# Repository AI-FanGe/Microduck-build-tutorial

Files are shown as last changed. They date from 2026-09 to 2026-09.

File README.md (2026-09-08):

# Microduck

<p align="center">
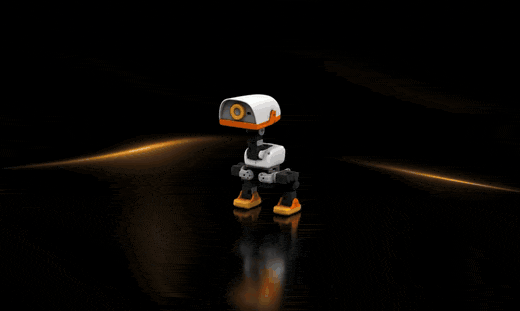
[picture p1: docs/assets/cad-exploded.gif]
Microduck 结构爆炸图
  
</p>
<p align="center">
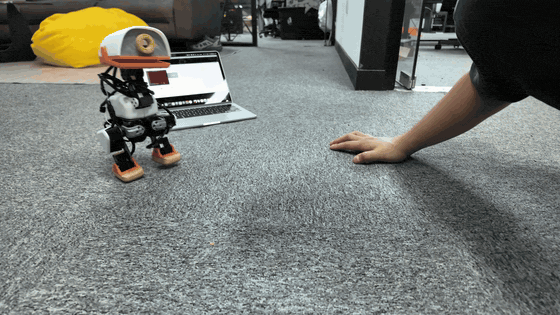
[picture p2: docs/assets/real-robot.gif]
Microduck 人机互动
  
</p>
<p align="center">
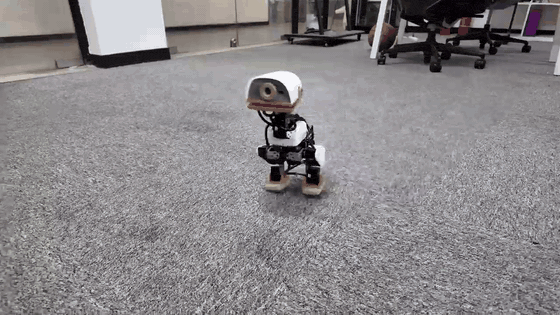
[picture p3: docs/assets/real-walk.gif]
Microduck 实机行走
  
</p>

Microduck 是一个小型双足机器人项目，包含两部分：

- `microduck/`: Raspberry Pi Zero 2 W 上运行的部署代码，负责读取 IMU、读取手柄/键盘输入、驱动 Dynamixel 舵机，并加载 ONNX 行走策略。
- `mjlab_microduck/`: 基于 MuJoCo/MjLab 的强化学习训练环境，用来训练并导出 `walk.onnx`。

本 README 面向装机和第一次运行：准备硬件、接线、刷写 `microduck.img.xz`、初始化 Wi-Fi、SSH 登录、运行模型，以及后续更新代码。3D打印的文件在项目中。

视频教程：https://www.youtube.com/watch?v=Vep8AjoCnEM

## 致谢

感谢开源项目 [microban](https://github.com/Rhoban/microban) 和 [microduck](https://github.com/pollen-robotics/microduck)。本项目的机械结构、部署思路、仿真训练和实机行走流程都受益于这些开源工作。

## 项目状态

当前发布镜像已经内置：

- Raspberry Pi OS Lite 64-bit。
- 主机名 `microduck`。
- 默认用户 `user`。
- 部署目录 `~/microduck`。
- Python 虚拟环境 `~/microduck/.venv`。
- 行走模型 `~/microduck/src/agents/walk.onnx`。
- 无头手柄服务 `microduck-gamepad.service`，可开机后用手柄启动模型。

当前预构建镜像：

- [microduck.img.xz](https://github.com/AI-FanGe/Microduck-build-tutorial/releases/download/image.v1/microduck.img.xz)

## BOM

下面是组装一台 Microduck 的主要物料。价格会随地区、采购渠道和批量变化，仅用于估算。

| 类别 | 物料 | 数量 | 说明 |
| :--- | :--- | :---: | :--- |
| 控制板 | Raspberry Pi Zero 2 W | 1 | 运行控制程序、蓝牙手柄、Wi-Fi 和 SSH。 |
| 舵机控制板 | ROBOTIS OpenRB-150 | 1 | 通过 USB 连接 Raspberry Pi，负责和 XL330 舵机总线通信。代码会优先自动查找 `/dev/serial/by-id/usb-ROBOTIS_OpenRB-150_*`。 |
| 舵机 | Dynamixel XL330-M288-T | 14 | 当前行走代码使用 14 个舵机：双腿 10 个，头/颈 4 个。若安装嘴部舵机，可使用 ID 15，但当前行走模型不依赖它。 |
| 电池 | 成品 6V 可充电电池 | 1 | 当前硬件直接使用成品 6V 电池包供电，不使用两节 18650 自制电池组。请确认电池能提供足够瞬时电流。 |
| 开关 | 电源开关 | 1 | 控制机器人主电源。 |
| 存储 | 16GB 或更大 microSD 卡 | 1 | 推荐使用质量稳定的新卡。镜像刷写后首次启动会自动扩展分区。 |
| IMU | BNO080/BNO085/BNO086 模块 | 1 | 通过 I2C 读取姿态，代码会自动探测常见地址。 |
| 结构件 | 3D 打印件 | 1 套 | 使用 `microduck/cad/` 中的模型打印。推荐 PLA。 |
| 螺丝 | M2/M2.5 自攻螺丝 | 若干 | 舵机固定、舵盘固定、结构件连接。建议多备。 |
| 线材 | Dynamixel 3-pin 线| 若干 | 舵机串联、电源连接、分线。 |

## 舵机 ID

控制代码期望的 ID 映射如下。烧录镜像之前或第一次运行之前，应先用 Dynamixel Wizard 设置好每个舵机。

| ID | 名称 | 位置 |
| :---: | :--- | :--- |
| 1 | `right_ankle` | 右踝 |
| 2 | `right_knee` | 右膝 |
| 3 | `right_hip_pitch` | 右髋俯仰 |
| 4 | `right_hip_roll` | 右髋横滚 |
| 5 | `right_hip_yaw` | 右髋偏航 |
| 6 | `left_ankle` | 左踝 |
| 7 | `left_knee` | 左膝 |
| 8 | `left_hip_pitch` | 左髋俯仰 |
| 9 | `left_hip_roll` | 左髋横滚 |
| 10 | `left_hip_yaw` | 左髋偏航 |
| 11 | `head_pitch` | 头部俯仰 |
| 12 | `neck_pitch` | 颈部俯仰 |
| 13 | `head_yaw` | 头部偏航 |
| 14 | `head_roll` | 头部横滚 |
| 15 | `mouth` | 可选嘴部舵机，当前行走策略不使用 |

Dynamixel Wizard 推荐参数：

- Protocol: `2.0`
- Baud Rate: `1Mbps`
- Return Delay Time: `0`
- PWM Slope: `255`
- Shutdown: 去掉输入电压错误触发项，避免电池电压波动时误停

## 接线图

### 电源接线

电源链路如下：

```mermaid
flowchart LR
    BAT[成品 6V 可充电电池] --> SW[电源开关]
    SW --> OPENRB[OpenRB-150 电源输入]
    OPENRB --> BUS[XL330 舵机总线]
    PI[Raspberry Pi Zero 2 W] -->|USB 数据线| OPENRB
    BAT --> REG[5V 稳压/USB 供电]
    REG --> PI
```

检查要点：

- 上电前用万用表确认正负极。
- 当前硬件使用成品 6V 可充电电池，不需要自制 2S 电池组、BMS 和 2S 充电板。
- OpenRB-150 负责 XL330 舵机通信，Raspberry Pi 通过 USB 连接 OpenRB-150。
- Raspberry Pi 需要稳定 5V 供电；舵机/OpenRB-150 使用 6V 电池侧供电。两侧必须共地，具体以你的电源模块和 OpenRB-150 接法为准。
- 焊点需要热缩管或热熔胶绝缘，避免短路。

### 舵机总线

XL330 使用 3-pin 串联总线。OpenRB-150 接出后可通过分线分到左右腿和头部。

```mermaid
flowchart TD
    OPENRB[OpenRB-150 Dynamixel Port]
    OPENRB --> SPLIT[分线]
    SPLIT --> R5[右腿链: ID 5 -> 4 -> 3 -> 2 -> 1]
    SPLIT --> L10[左腿链: ID 10 -> 9 -> 8 -> 7 -> 6]
    SPLIT --> H12[头颈链: ID 12 -> 11 -> 13 -> 14]
```

注意：

- 舵机顺序可以按结构方便布线，但 ID 必须和上表一致。
- 如果总线上有通信错误，优先检查 OpenRB-150 是否枚举成功、电池电压、GND、线序和舵机 ID。
- 正常情况下代码会自动选择 OpenRB-150 的 USB 串口；如果没有找到，会回退到 `/dev/ttyACM0`、`/dev/serial0`、`/dev/ttyAMA0` 或 `/dev/ttyS0`。

### IMU 接线

BNO08x 模块走 I2C：

| IMU 引脚 | Raspberry Pi / Hat |
| :--- | :--- |
| `VIN` / `3V3` | 3.3V，按模块标识选择 |
| `GND` | GND |
| `SDA` | GPIO2 / I2C SDA |
| `SCL` | GPIO3 / I2C SCL |

软件默认使用 I2C bus `1`，会自动寻找 BNO08x 常见地址。安装方向由 `IMU_MOUNT_QUAT` 配置，已经和当前行走模型匹配。

## 使用 `microduck.img.xz`

### 1. 校验镜像

下载或拷贝镜像后，建议先校验：

```bash
sha256sum microduck.img.xz
```

应与发布页面或上文给出的 SHA256 一致。

### 2. 刷写 SD 卡

推荐使用 Raspberry Pi Imager：

1. 插入 microSD 卡。
2. 打开 Raspberry Pi Imager。
3. `Choose Device` 选择 `Raspberry Pi Zero 2 W`。
4. `Choose OS` 选择 `Use custom`，选中 `microduck.img.xz`。
5. `Choose Storage` 选择目标 microSD 卡。
6. 如果提示是否应用 OS customization，选择 `No`。
7. 点击 `Write`，等待写入和验证完成。

Linux 命令行也可以刷写，但要非常确认设备名：

```bash
lsblk
xzcat microduck.img.xz | sudo dd of=/dev/sdX bs=4M status=progress conv=fsync
```

把 `/dev/sdX` 换成你的 SD 卡设备，不要写成电脑硬盘。

### 3. 初始化 Wi-Fi

两种方法任选其一。Pi Zero 2 W 只支持 2.4GHz Wi-Fi，不要使用纯 5GHz 网络。

#### 方法 1：在电脑上编辑 SD 卡

刷写完成后，拔下再插回 SD 卡。Ubuntu 通常会挂载出两个分区：

- `bootfs`: 启动分区，可直接编辑 Wi-Fi 配置。
- `rootfs`: 系统根分区，一般不需要手动改。

编辑：

```bash
sudo nano /media/$USER/bootfs/network-config
```

内容类似：

```yaml
network:
  version: 2
  ethernets:
    eth0:
      dhcp4: true
      dhcp6: true
      optional: true
  wifis:
    wlan0:
      dhcp4: true
      regulatory-domain: "<YOUR_COUNTRY_CODE>"
      access-points:
        "<YOUR_WIFI_NAME>":
          password: "<YOUR_WIFI_PASSWORD>"
      optional: true
```

把三处占位符改掉：

- `<YOUR_COUNTRY_CODE>`: 两位国家/地区代码，例如 `CN`、`US`、`GB`、`FR`。
- `<YOUR_WIFI_NAME>`: Wi-Fi 名称。
- `<YOUR_WIFI_PASSWORD>`: Wi-Fi 密码。

可配置多个 Wi-Fi：

```yaml
      access-points:
        "HomeWifi":
          password: "home-password"
        "PhoneHotspot":
          password: "hotspot-password"
```

保存后安全弹出 SD 卡，插入机器人，打开电源。

#### 方法 2：插上 HDMI 和键盘，在 Pi 上用 nmcli

刷写完成后把 SD 卡插入 Pi，接上 mini HDMI 显示器和 USB 键盘（Zero 需要 OTG 转接头）。镜像是 Raspberry Pi OS Lite，没有桌面，开机后是终端登录。

第一次启动会扩展分区，等待 1 到 3 分钟，不要断电。出现登录提示后：

```text
用户名: user
密码:   password
```

输入密码时屏幕不会显示字符，直接回车。然后扫描并连接 Wi-Fi，设为开机自动连接：

```bash
nmcli device wifi list
sudo nmcli device wifi connect "你的WiFi名字" password "你的WiFi密码"
sudo nmcli con mod "你的WiFi名字" wifi.powersave disable
sudo nmcli con mod "你的WiFi名字" connection.autoconnect yes
```

检查是否连上、是否自动连接：

```bash
nmcli -t -f NAME,TYPE,AUTOCONNECT,DEVICE connection show
hostname -I
```

`AUTOCONNECT` 应为 `yes`，并且已经拿到 IP。之后每次开机都会自动连这个 Wi-Fi。

## 首次启动

第一次启动会做几件事：

- 扩展文件系统到整张 SD 卡。
- 重新生成 SSH host keys。
- 读取 `network-config` 并连接 Wi-Fi（方法 1）。若用方法 2，首次启动后再用 `nmcli` 配置。
- 启动后台手柄服务。

等待 1 到 3 分钟，然后在电脑上测试：

```bash
ping microduck.local
```

如果 `.local` 解析失败，到路由器后台查看 Pi 的 IP，然后用 IP 登录。

默认登录：

```bash
ssh user@microduck.local
```

默认密码：

```text
password
```

第一次登录后建议立刻改密码：

```bash
passwd
```

## 第一次运行模型

### SSH 模式

在电脑上远程登录 Pi。Windows 用 PowerShell，Linux / macOS 用终端：

```bash
ssh user@microduck.local
```

默认密码是 `password`。如果提示 `REMOTE HOST IDENTIFICATION HAS CHANGED`，先清掉旧记录再重连：

```bash
ssh-keygen -R microduck.local
```

登录成功后，把机器人放在稳定平面上或扶住，然后启动控制程序：

```bash
cd ~/microduck
PYTHONPATH=src .venv/bin/python src/main.py
```

启动后程序会：

1. 打开舵机扭矩。
2. 平滑回到 neutral pose。
3. 读取键盘或手柄输入。
4. 加载 `src/agents/walk.onnx` 行走策略。

键盘控制：

| 按键 | 功能 |
| :--- | :--- |
| `v` | 开启/关闭行走 |
| 方向键上/下 | 前进/后退 |
| 方向键左/右 | 左右转向 |
| `x` | 速度归零 |
| `i` | 显示/隐藏 IMU 信息 |
| `q` | 停止控制循环 |

### 远程 SSH 运行

电脑和机器人连同一个 2.4GHz Wi-Fi 后，在 Windows PowerShell 或 Linux / macOS 终端执行：

```bash
ssh user@microduck.local
```

登录后：

```bash
cd ~/microduck
PYTHONPATH=src .venv/bin/python src/main.py
```

停止：按 `q`。如果程序还在跑，另开一个 SSH 窗口：

```bash
ssh user@microduck.local
cd ~/microduck
PYTHONPATH=src .venv/bin/python src/stop.py
```

安全关机：

```bash
ssh user@microduck.local
sudo shutdown -h now
```

不要直接断电。先关机，等 10 到 15 秒，再关闭电源开关。

## 手柄模式

### 配对蓝牙手柄

SSH 到 Pi 后：

```bash
bluetoothctl
```

在 `bluetoothctl` 里执行：

```text
power on
agent on
scan on
pair XX:XX:XX:XX:XX:XX
trust XX:XX:XX:XX:XX:XX
connect XX:XX:XX:XX:XX:XX
scan off
quit
```

把 `XX:XX:XX:XX:XX:XX` 换成扫描到的手柄 MAC 地址。

### 无头运行

镜像里已经启用无头手柄服务。开机后：

| 操作 | 功能 |
| :--- | :--- |
| 按住 `START` 2 秒 | 启动控制循环 |
| `A` | 开启/关闭行走 |
| 左摇杆 | 前后/左右速度 |
| 右摇杆左右 | 原地或行进中转向 |
| `B` | 停止控制循环 |
| 同时按住左右扳机 2 秒 | 安全关机 |

手柄连接时，服务会关闭 Wi-Fi 以改善 2.4GHz 蓝牙稳定性。需要 SSH 时，先关闭手柄，Wi-Fi 会自动恢复。

## 常用命令

在开发电脑的 `microduck/` 目录下：

| 命令 | 说明 |
| :--- | :--- |
| `make sync` | 同步本地部署代码到 Pi 的 `~/microduck`。 |
| `make setup` | 同步代码并在 Pi 上执行 `uv sync --frozen`。改依赖后使用。 |
| `make run` | 同步并启动控制循环。 |
| `make stop` | 停止控制循环。 |
| `make shutdown` | 安全关闭 Pi。 |
| `make imu` | 查看 IMU/gyro 数据。 |
| `make voltage` | 查看舵机电压。 |
| `make voltage ID=2` | 查看指定舵机电压。 |
| `make gamepad-headless-enable` | 安装并启用无头手柄服务。 |
| `make gamepad-headless-disable` | 禁用无头手柄服务。 |

## 更新模型

训练仓 `mjlab_microduck/` 导出的 ONNX 模型应放到：

```bash
microduck/src/agents/walk.onnx
```

更新后同步：

```bash
cd microduck
make sync
```

下一次运行会加载新的 `walk.onnx`。

## 重新制作发布镜像

当 Pi 上的系统、依赖、服务和模型都确认可用后，可以把这张 SD 卡做成新的 `microduck.img.xz`。

推荐流程：

1. 先用当前 SD 卡实机测试 `make run` 或手柄无头运行。
2. 关机，把 SD 卡插回电脑。
3. 克隆整张卡到本地 `.img` 文件。
4. 只在镜像副本里清理敏感信息：
   - Wi-Fi 配置。
   - SSH host keys。
   - 用户 SSH key。
   - `/etc/machine-id`。
   - cloud-init 状态。
   - shell history、日志、apt 缓存。
5. 重置 `bootfs/network-config` 为占位模板。
6. 确认 `~/microduck/src/agents/walk.onnx`、`.venv`、`microduck-gamepad.service` 都存在。
7. 用 PiShrink 压缩生成 `microduck.img.xz`。
8. 计算 SHA256，并把校验值记录到 README 或 Release 说明里。

本仓库已有详细步骤：

```bash
microduck/docs/dev/clone_sd.md
```

## 目录结构

```text
.
├── README.md
├── microduck/
│   ├── Makefile
│   ├── src/
│   │   ├── main.py
│   │   ├── scheduler.py
│   │   ├── robot_controller.py
│   │   ├── imu_reader.py
│   │   ├── agents/walk.onnx
│   │   └── moves/walk.py
│   ├── systemd/
│   └── docs/
└── mjlab_microduck/
    ├── src/mjlab_microduck/
    └── logs/
```

## 故障排查

### 找不到 `microduck.local`

先等 1 到 3 分钟。仍找不到时：

- 确认 Wi-Fi 是 2.4GHz。
- 确认 `network-config` YAML 缩进没变（方法 1）。
- 若用方法 2，在 Pi 上执行 `nmcli device wifi list` 和 `hostname -I` 确认已连上 2.4GHz 并拿到 IP。
- 到路由器后台查 Pi 的 IP。
- 用 `ssh user@<IP>` 登录。

### SSH 提示 host key changed

发布镜像首次启动会重新生成 SSH host keys。如果同一台电脑以前连过另一张卡，清理本机记录：

```bash
ssh-keygen -R microduck.local
ssh-keygen -R <IP>
```

### 舵机不动或通信错误

检查：

- 电池电压是否正常。
- OpenRB-150、舵机总线和 Raspberry Pi 供电/GND 是否正确。
- 舵机 ID 是否符合上表。
- Dynamixel 波特率是否为 1Mbps。
- OpenRB-150 的 USB 串口是否能被识别。
- 线序、分线和插头方向是否正确。

### 手柄连接后 SSH 断开

这是无头模式的设计：手柄连接后会关闭 Wi-Fi，提升蓝牙稳定性。关闭手柄后 Wi-Fi 会恢复。

### 机器人一启动就容易倒

先手扶机器人运行，确认：

- 左右腿舵机 ID 没有装反。
- 膝盖 offset 与实际装配一致。
- IMU 安装方向正确。
- `walk.onnx` 是当前硬件对应的模型。

## 安全提示

- 第一次运行一定要扶住机器人。
- 不要在桌边或高处测试。
- 不要在电池低电压时长时间运行。
- 不要直接断电，先执行 `make shutdown` 或手柄安全关机。
- 充电和上电前检查短路、极性和焊点绝缘。

---

# Microduck (English)

<p align="center">
  Microduck exploded view
</p>
<p align="center">
  Microduck human-robot interaction
</p>
<p align="center">
  Microduck walking
</p>

Microduck is a compact biped robot project. This repository presents one practical hardware and software setup for running an ONNX reinforcement learning walking policy on real Dynamixel XL330 servos.

The project contains two main parts:

- `microduck/`: deployment code for the Raspberry Pi Zero 2 W. It reads the IMU, reads keyboard or gamepad commands, drives Dynamixel servos, and loads the ONNX walking policy.
- `mjlab_microduck/`: reinforcement learning training environment based on MuJoCo/MjLab. It is used to train and export `walk.onnx`.

This README covers the full first-time workflow: hardware, wiring, flashing `microduck.img.xz`, Wi-Fi setup, first SSH login, first run, day-to-day usage, and rebuilding a release image.

## Acknowledgements

Thanks to the open-source projects [microban](https://github.com/Rhoban/microban) and [microduck](https://github.com/pollen-robotics/microduck). This project benefits from their mechanical design, deployment ideas, simulation training work, and real-robot walking pipeline.

## Project Status

The current release image includes:

- Raspberry Pi OS Lite 64-bit.
- Hostname `microduck`.
- Default user `user`.
- Deployment directory `~/microduck`.
- Python virtual environment `~/microduck/.venv`.
- Walking model `~/microduck/src/agents/walk.onnx`.
- Headless gamepad service `microduck-gamepad.service`, so the walking controller can be started from a gamepad after boot.

Current prebuilt image:

- [microduck.img.xz](https://github.com/AI-FanGe/Microduck-build-tutorial/releases/download/image.v1/microduck.img.xz)

SHA256:

```text
096885dc32fb5b1db2ad69ba6bea868d8ab988f2b47c0d884eb63ba0dfdcb5c4
```

## BOM

The following is the main bill of materials for building one Microduck. Prices vary by region, supplier, and quantity, so treat them as estimates.

| Category | Part | Qty | Notes |
| :--- | :--- | :---: | :--- |
| Main controller | Raspberry Pi Zero 2 W | 1 | Runs the control program, Bluetooth gamepad, Wi-Fi, and SSH. |
| Servo controller | ROBOTIS OpenRB-150 | 1 | Connected to the Raspberry Pi over USB. It communicates with the XL330 servo bus. The code first looks for `/dev/serial/by-id/usb-ROBOTIS_OpenRB-150_*`. |
| Servos | Dynamixel XL330-M288-T | 14 | The current walking code uses 14 servos: 10 for the legs and 4 for the head/neck. An optional mouth servo can use ID 15, but the walking policy does not depend on it. |
| Battery | Ready-made 6V rechargeable battery | 1 | This hardware setup uses a ready-made 6V battery pack, not a custom two-cell pack. Make sure the battery can provide enough peak current. |
| Switch | Power switch | 1 | Main power switch for the robot. |
| Storage | 16GB or larger microSD card | 1 | Use a reliable new card. The image expands the filesystem on first boot. |
| IMU | BNO080/BNO085/BNO086 module | 1 | Read over I2C. The code auto-detects common BNO08x addresses. |
| Mechanical parts | 3D-printed parts | 1 set | Print from the models under `microduck/cad/`. PLA is recommended. |
| Screws | M2/M2.5 self-tapping screws | Several | Used for servo mounting, horn mounting, and structural assembly. Keep extras. |
| Bearings/shims | POM shims and steel shims | Several | Low-cost rotational support. |
| Cables | Dynamixel 3-pin cables, JST wires, power connectors | Several | Servo daisy chains, power wiring, and splitters. |
| Setup tools | Dynamixel U2D2 + U2D2 Power Hub | 1 set | Used to configure servo IDs, baud rate, and parameters. One set can be shared across multiple robots. |

Recommended extras:

- Spare XL330 servos, spare 6V battery, power wires, and Dynamixel cables.
- JST-EH terminals, crimping tool, heat-shrink tubing, and hot glue.
- A multimeter for checking polarity and battery voltage.

## Servo IDs

The deployment code expects the following ID mapping. Configure every servo with Dynamixel Wizard before the first run.

| ID | Name | Position |
| :---: | :--- | :--- |
| 1 | `right_ankle` | Right ankle |
| 2 | `right_knee` | Right knee |
| 3 | `right_hip_pitch` | Right hip pitch |
| 4 | `right_hip_roll` | Right hip roll |
| 5 | `right_hip_yaw` | Right hip yaw |
| 6 | `left_ankle` | Left ankle |
| 7 | `left_knee` | Left knee |
| 8 | `left_hip_pitch` | Left hip pitch |
| 9 | `left_hip_roll` | Left hip roll |
| 10 | `left_hip_yaw` | Left hip yaw |
| 11 | `head_pitch` | Head pitch |
| 12 | `neck_pitch` | Neck pitch |
| 13 | `head_yaw` | Head yaw |
| 14 | `head_roll` | Head roll |
| 15 | `mouth` | Optional mouth servo, not used by the current walking policy |

Recommended Dynamixel Wizard settings:

- Protocol: `2.0`
- Baud Rate: `1Mbps`
- Return Delay Time: `0`
- PWM Slope: `255`
- Shutdown: remove the input-voltage-error trigger to avoid unwanted shutdowns during battery voltage dips

## Wiring

### Power Wiring

The power path is:

```mermaid
flowchart LR
    BAT[Ready-made 6V rechargeable battery] --> SW[Power switch]
    SW --> OPENRB[OpenRB-150 power input]
    OPENRB --> BUS[XL330 servo bus]
    PI[Raspberry Pi Zero 2 W] -->|USB data cable| OPENRB
    BAT --> REG[5V regulator / USB power]
    REG --> PI
```

Checklist:

- Check polarity with a multimeter before powering on.
- This setup uses a ready-made 6V rechargeable battery. It does not require a custom two-cell battery pack, BMS, or 2S charger board.
- OpenRB-150 handles XL330 servo communication. The Raspberry Pi connects to it over USB.
- The Raspberry Pi needs stable 5V power. The servos/OpenRB-150 are powered from the 6V battery side. Grounds must be common. Follow your actual regulator and OpenRB-150 wiring.
- Insulate solder joints with heat-shrink tubing or hot glue to prevent shorts.

### Servo Bus

XL330 servos use a 3-pin daisy-chain bus. The OpenRB-150 output can be split into the right leg, left leg, and head/neck chains.

```mermaid
flowchart TD
    OPENRB[OpenRB-150 Dynamixel Port]
    OPENRB --> SPLIT[Splitter]
    SPLIT --> R5[Right leg chain: ID 5 -> 4 -> 3 -> 2 -> 1]
    SPLIT --> L10[Left leg chain: ID 10 -> 9 -> 8 -> 7 -> 6]
    SPLIT --> H12[Head/neck chain: ID 12 -> 11 -> 13 -> 14]
```

Notes:

- The physical cable order can follow the mechanical layout, but the servo IDs must match the table above.
- If the bus has communication errors, first check that the OpenRB-150 enumerates correctly, then check battery voltage, ground, cable order, and servo IDs.
- Normally the code automatically selects the OpenRB-150 USB serial port. If not found, it falls back to `/dev/ttyACM0`, `/dev/serial0`, `/dev/ttyAMA0`, or `/dev/ttyS0`.

### IMU Wiring

The BNO08x module uses I2C:

| IMU Pin | Raspberry Pi / Hat |
| :--- | :--- |
| `VIN` / `3V3` | 3.3V, depending on the module label |
| `GND` | GND |
| `SDA` | GPIO2 / I2C SDA |
| `SCL` | GPIO3 / I2C SCL |

The software uses I2C bus `1` by default and auto-detects common BNO08x addresses. The mounting orientation is configured by `IMU_MOUNT_QUAT`, which is already matched to the current walking model.

## Using `microduck.img.xz`

### 1. Verify the Image

After downloading or copying the image, verify it:

```bash
sha256sum microduck.img.xz
```

The result should match the SHA256 published with the image.

### 2. Flash the SD Card

Raspberry Pi Imager is recommended:

1. Insert the microSD card.
2. Open Raspberry Pi Imager.
3. Select `Choose Device` -> `Raspberry Pi Zero 2 W`.
4. Select `Choose OS` -> `Use custom`, then choose `microduck.img.xz`.
5. Select `Choose Storage`, then choose the target microSD card.
6. If asked whether to apply OS customization settings, choose `No`.
7. Click `Write` and wait for writing and verification to complete.

You can also flash from the Linux command line. Be very careful with the device name:

```bash
lsblk
xzcat microduck.img.xz | sudo dd of=/dev/sdX bs=4M status=progress conv=fsync
```

Replace `/dev/sdX` with your SD card device. Do not write to your computer's internal disk.

### 3. Initialize Wi-Fi

Use either method. The Raspberry Pi Zero 2 W only supports 2.4GHz Wi-Fi. Do not use a 5GHz-only network.

#### Method 1: Edit the SD card on a computer

After flashing, unplug and reinsert the SD card. Ubuntu usually mounts two partitions:

- `bootfs`: boot partition, where Wi-Fi can be configured.
- `rootfs`: root filesystem, usually no manual edits are needed.

Edit:

```bash
sudo nano /media/$USER/bootfs/network-config
```

The file looks like this:

```yaml
network:
  version: 2
  ethernets:
    eth0:
      dhcp4: true
      dhcp6: true
      optional: true
  wifis:
    wlan0:
      dhcp4: true
      regulatory-domain: "<YOUR_COUNTRY_CODE>"
      access-points:
        "<YOUR_WIFI_NAME>":
          password: "<YOUR_WIFI_PASSWORD>"
      optional: true
```

Replace:

- `<YOUR_COUNTRY_CODE>`: two-letter country code, such as `CN`, `US`, `GB`, or `FR`.
- `<YOUR_WIFI_NAME>`: Wi-Fi name.
- `<YOUR_WIFI_PASSWORD>`: Wi-Fi password.

Multiple Wi-Fi networks can be configured:

```yaml
      access-points:
        "HomeWifi":
          password: "home-password"
        "PhoneHotspot":
          password: "hotspot-password"
```

Save the file, safely eject the SD card, insert it into the robot, and power on.

#### Method 2: HDMI and keyboard, then nmcli on the Pi

After flashing, insert the SD card into the Pi and connect a mini HDMI display plus a USB keyboard (the Zero needs a USB OTG adapter). The image is Raspberry Pi OS Lite, so there is no desktop — only a terminal login.

The first boot expands the partition. Wait 1 to 3 minutes and do not power off. When the login prompt appears:

```text
username: user
password: password
```

The password is not echoed. Then scan, connect, and enable autoconnect:

```bash
nmcli device wifi list
sudo nmcli device wifi connect "YOUR_WIFI_NAME" password "YOUR_WIFI_PASSWORD"
sudo nmcli con mod "YOUR_WIFI_NAME" wifi.powersave disable
sudo nmcli con mod "YOUR_WIFI_NAME" connection.autoconnect yes
```

Check that it is connected and set to autoconnect:

```bash
nmcli -t -f NAME,TYPE,AUTOCONNECT,DEVICE connection show
hostname -I
```

`AUTOCONNECT` should be `yes`, and the Pi should have an IP address. After that, this Wi-Fi will connect automatically on every boot.

## First Boot

On first boot, the image will:

- Expand the filesystem to the full SD card.
- Regenerate SSH host keys.
- Read `network-config` and join Wi-Fi (method 1). If you use method 2, configure Wi-Fi with `nmcli` after the first boot.
- Start the background gamepad service.

Wait 1 to 3 minutes, then test from your computer:

```bash
ping microduck.local
```

If `.local` does not resolve, check your router's DHCP client list and use the Pi's IP address.

Default login:

```bash
ssh user@microduck.local
```

Default password:

```text
password
```

Change the password after the first login:

```bash
passwd
```

## First Run

### SSH Mode

Log in to the Pi from a computer. Use PowerShell on Windows, or a terminal on Linux / macOS:

```bash
ssh user@microduck.local
```

The default password is `password`. If SSH says `REMOTE HOST IDENTIFICATION HAS CHANGED`, clear the old host key and try again:

```bash
ssh-keygen -R microduck.local
```

After login, place the robot on a stable surface or hold it, then start the control program:

```bash
cd ~/microduck
PYTHONPATH=src .venv/bin/python src/main.py
```

On startup, the program will:

1. Enable servo torque.
2. Smoothly move to the neutral pose.
3. Read keyboard or gamepad input.
4. Load `src/agents/walk.onnx`.

Keyboard controls:

| Key | Action |
| :--- | :--- |
| `v` | Toggle walking |
| Up/down arrows | Forward/backward |
| Left/right arrows | Turn left/right |
| `x` | Zero velocity |
| `i` | Show/hide IMU status |
| `q` | Stop the control loop |

### Remote SSH

After the computer and the robot are on the same 2.4GHz Wi-Fi, run this in Windows PowerShell or a Linux / macOS terminal:

```bash
ssh user@microduck.local
```

Then:

```bash
cd ~/microduck
PYTHONPATH=src .venv/bin/python src/main.py
```

Stop with `q`. If the program is still running, open another SSH session:

```bash
ssh user@microduck.local
cd ~/microduck
PYTHONPATH=src .venv/bin/python src/stop.py
```

Safe shutdown:

```bash
ssh user@microduck.local
sudo shutdown -h now
```

Do not cut power directly. Shut the Pi down first, wait 10 to 15 seconds, then turn off the power switch.

## Gamepad Mode

### Pair a Bluetooth Gamepad

SSH into the Pi, then run:

```bash
bluetoothctl
```

Inside `bluetoothctl`:

```text
power on
agent on
scan on
pair XX:XX:XX:XX:XX:XX
trust XX:XX:XX:XX:XX:XX
connect XX:XX:XX:XX:XX:XX
scan off
quit
```

Replace `XX:XX:XX:XX:XX:XX` with the detected controller MAC address.

### Headless Operation

The image already enables the headless gamepad service. After boot:

| Action | Function |
| :--- | :--- |
| Hold `START` for 2 seconds | Start the control loop |
| `A` | Toggle walking |
| Left stick | Forward/backward and lateral velocity |
| Right stick left/right | Turning |
| `B` | Stop the control loop |
| Hold both triggers for 2 seconds | Safe shutdown |

When the gamepad is connected, the service disables Wi-Fi to improve 2.4GHz Bluetooth stability. Turn off the controller when you need SSH; Wi-Fi will be restored automatically.

## Common Commands

Run these from the `microduck/` directory on your development computer:

| Command | Description |
| :--- | :--- |
| `make sync` | Sync local deployment code to `~/microduck` on the Pi. |
| `make setup` | Sync code and run `uv sync --frozen` on the Pi. Use after dependency changes. |
| `make run` | Sync and start the control loop. |
| `make stop` | Stop the control loop. |
| `make shutdown` | Safely shut down the Pi. |
| `make imu` | Print IMU/gyro data. |
| `make voltage` | Read servo voltage. |
| `make voltage ID=2` | Read voltage from a specific servo. |
| `make gamepad-headless-enable` | Install and enable the headless gamepad service. |
| `make gamepad-headless-disable` | Disable the headless gamepad service. |

## Updating the Model

The ONNX model exported from `mjlab_microduck/` should be placed at:

```bash
microduck/src/agents/walk.onnx
```

Then sync:

```bash
cd microduck
make sync
```

The next run will load the new `walk.onnx`.

## Rebuilding a Release Image

After the Pi system, dependencies, services, and model have been tested, the SD card can be turned into a new `microduck.img.xz`.

Recommended workflow:

1. Test `make run` or headless gamepad mode on the real robot.
2. Shut down the Pi and insert the SD card into your computer.
3. Clone the full card to a local `.img` file.
4. Clean sensitive information only inside the cloned image:
   - Wi-Fi credentials.
   - SSH host keys.
   - User SSH keys.
   - `/etc/machine-id`.
   - cloud-init state.
   - shell history, logs, and apt cache.
5. Reset `bootfs/network-config` to placeholder values.
6. Verify that `~/microduck/src/agents/walk.onnx`, `.venv`, and `microduck-gamepad.service` exist.
7. Use PiShrink to create `microduck.img.xz`.
8. Compute SHA256 and record the checksum in the README or Release notes.

Detailed steps are in:

```bash
microduck/docs/dev/clone_sd.md
```

## Directory Layout

```text
.
├── README.md
├── microduck/
│   ├── Makefile
│   ├── src/
│   │   ├── main.py
│   │   ├── scheduler.py
│   │   ├── robot_controller.py
│   │   ├── imu_reader.py
│   │   ├── agents/walk.onnx
│   │   └── moves/walk.py
│   ├── systemd/
│   └── docs/
└── mjlab_microduck/
    ├── src/mjlab_microduck/
    └── logs/
```

## Troubleshooting

### `microduck.local` Cannot Be Found

Wait 1 to 3 minutes first. If it still cannot be found:

- Make sure the Wi-Fi is 2.4GHz.
- Make sure the YAML indentation in `network-config` is unchanged (method 1).
- If you used method 2, run `nmcli device wifi list` and `hostname -I` on the Pi to confirm it joined 2.4GHz Wi-Fi and has an IP.
- Check the Pi's IP address in your router.
- Login with `ssh user@<IP>`.

### SSH Says Host Key Changed

The release image regenerates SSH host keys on first boot. If your computer previously connected to another card, clear the local entry:

```bash
ssh-keygen -R microduck.local
ssh-keygen -R <IP>
```

### Servos Do Not Move or Communication Fails

Check:

- Battery voltage.
- OpenRB-150, servo bus, Raspberry Pi power, and common ground.
- Servo IDs match the table above.
- Dynamixel baud rate is 1Mbps.
- OpenRB-150 USB serial port is detected.
- Cable order, splitters, and connector direction.

### SSH Disconnects When the Gamepad Connects

This is expected in headless mode. The service disables Wi-Fi when the gamepad is connected to improve Bluetooth stability. Turn off the controller and Wi-Fi will be restored.

### The Robot Falls Immediately

Hold the robot first, then check:

- Left/right leg servo IDs are not swapped.
- Knee offsets match the physical assembly.
- IMU mounting orientation is correct.
- `walk.onnx` matches the current hardware.

## Safety Notes

- Hold the robot during the first run.
- Do not test near the edge of a table.
- Do not run for a long time on low battery.
- Do not cut power directly. Use `make shutdown` or the gamepad shutdown gesture first.
- Before charging or powering on, check for shorts, polarity, and insulation.

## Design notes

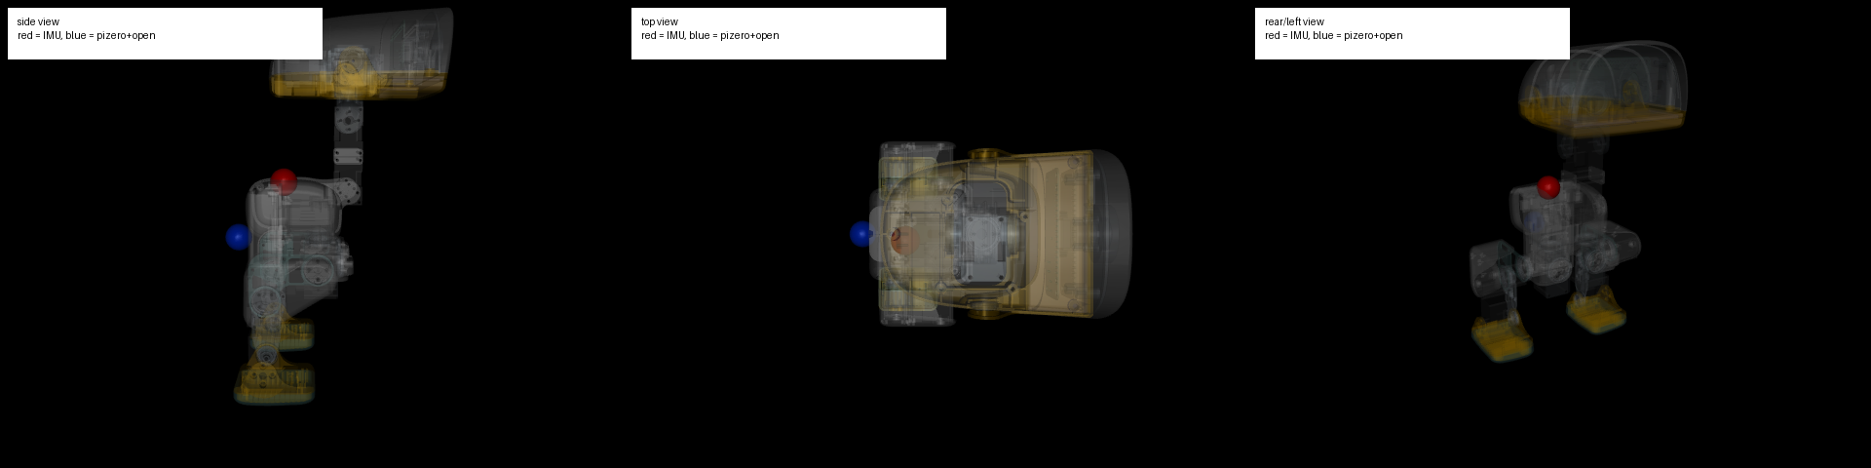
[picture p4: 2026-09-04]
mjlab_microduck/imu_marker_trunk_views.png

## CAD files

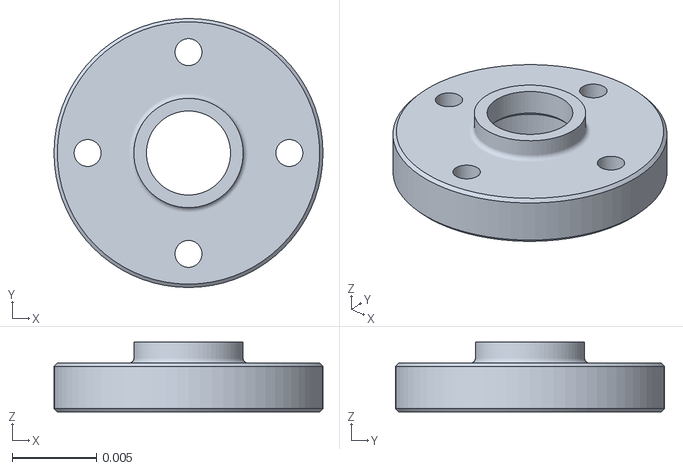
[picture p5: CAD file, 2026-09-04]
microduck/src/model/mjcf/assets/dc15_a01_horn_idle2_dummy.stl
0.016 x 0.016 x 0.00415

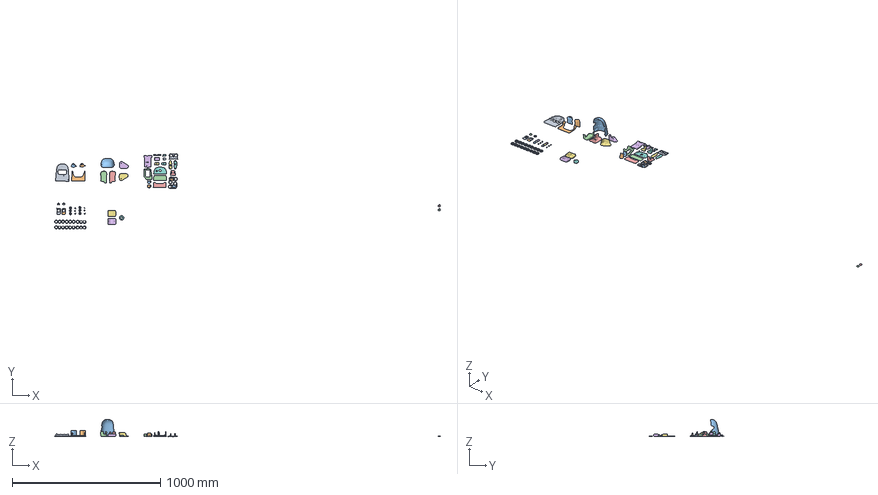
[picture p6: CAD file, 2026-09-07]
microduck3D打印.3mf
2603.7 x 508.5 x 116.1 mm
3.obj
4.obj
5.obj
7.obj
8.obj
a.obj
b.obj x 2
d.obj
e.obj
f.obj
g.obj
h.obj
i.obj
j.obj
k.obj
l.obj
m.obj
n.obj
o.obj
p.obj
q.obj
111.obj
222.obj
333.obj
dfvdfb.obj x 2
ersgtbgertgestrg.obj x 18
idle_horn.stl x 8
idle_cap.stl x 6
rgbn.obj x 2
grbrgn.obj
thngthm.obj
dfbdfbbbbb1.obj
fgb.obj
gbgb.obj
ghmghmghmghm.obj

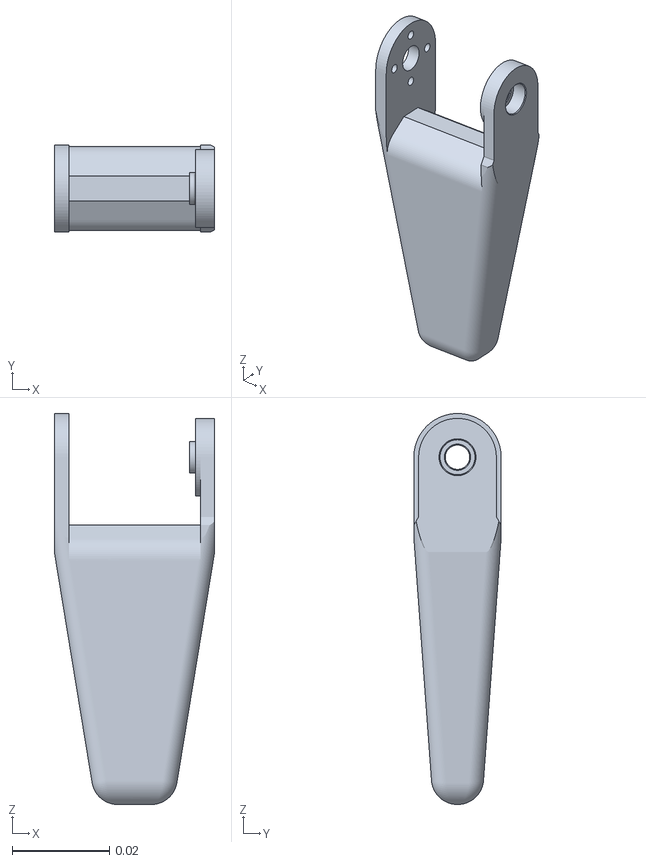
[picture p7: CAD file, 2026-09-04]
microduck/src/model/mjcf/assets/radius.stl
0.033 x 0.018 x 0.0805

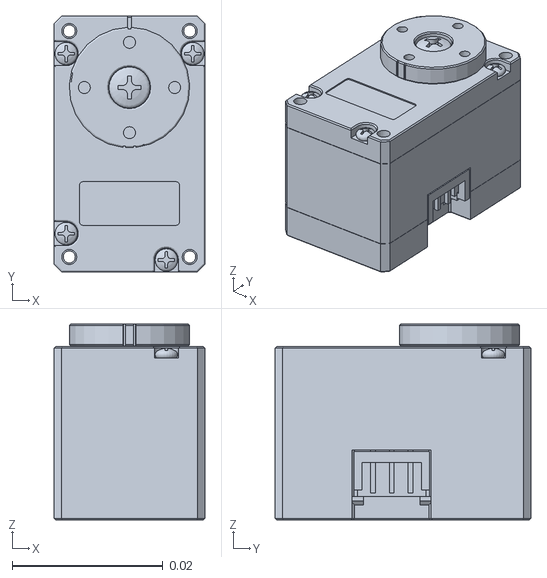
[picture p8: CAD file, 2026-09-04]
microduck/src/model/mjcf/assets/xl330_without_horn.stl
0.02 x 0.034 x 0.026

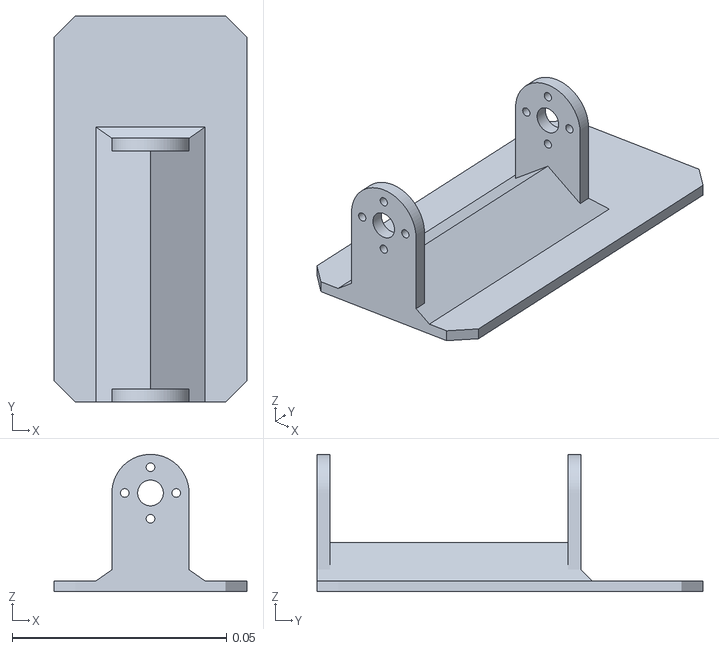
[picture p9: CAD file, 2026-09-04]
microduck/src/model/mjcf/assets/foot__configuration_right.stl
0.045 x 0.09 x 0.032

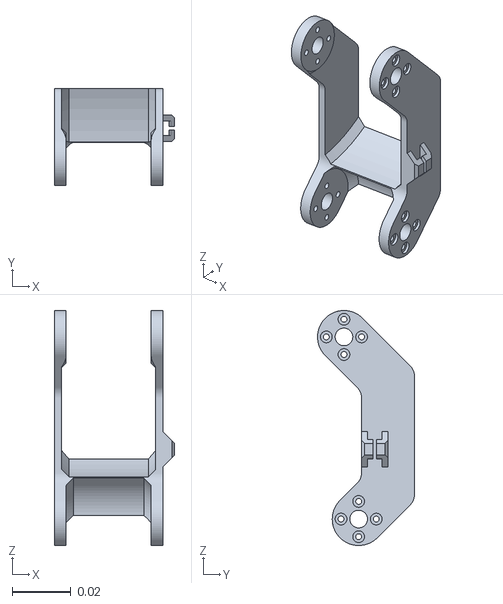
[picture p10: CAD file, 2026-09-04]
microduck/src/model/mjcf/assets/femur__configuration_right.stl
0.041 x 0.033 x 0.08

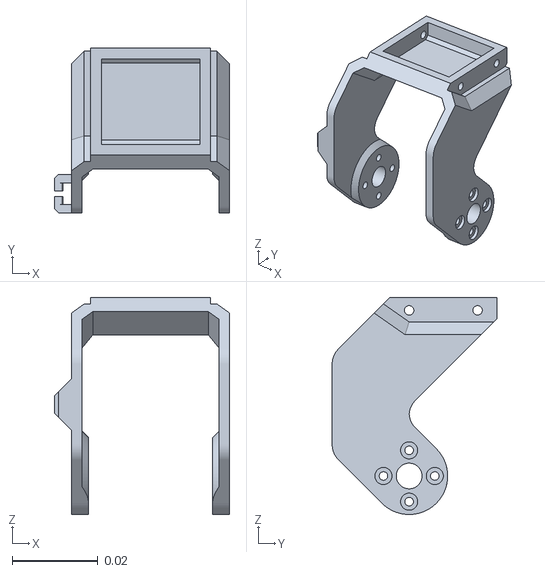
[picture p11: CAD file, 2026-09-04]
microduck/src/model/mjcf/assets/tibia__configuration_left.stl
0.041 x 0.0385 x 0.0507

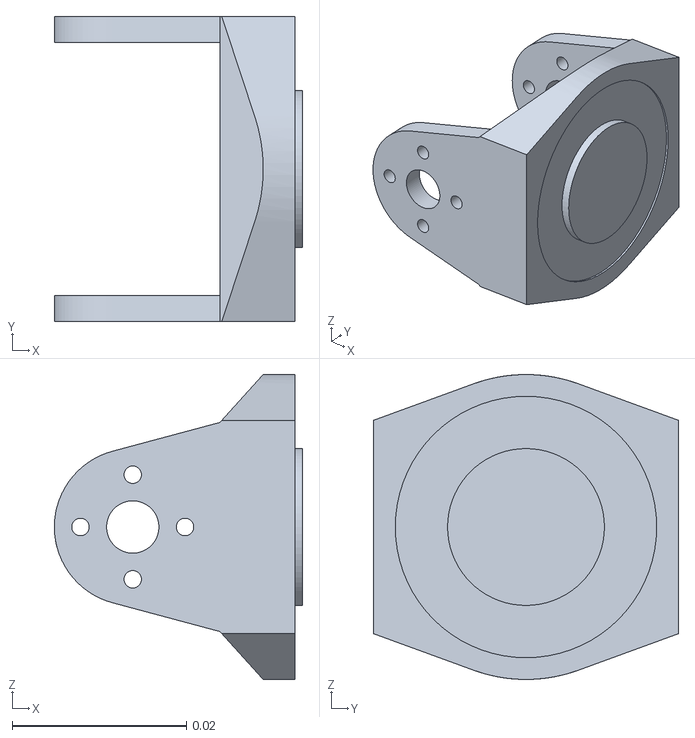
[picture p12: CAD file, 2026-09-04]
microduck/src/model/mjcf/assets/shoulder.stl
0.0285 x 0.035 x 0.035

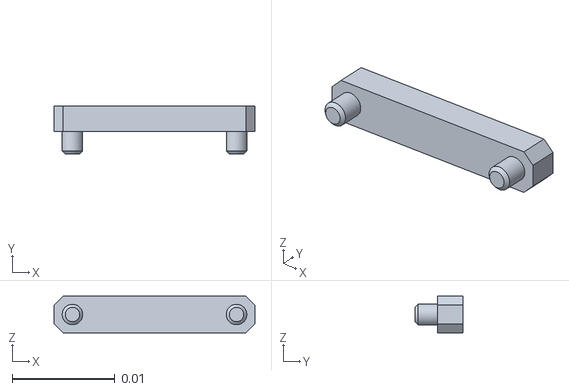
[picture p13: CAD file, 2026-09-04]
microduck/src/model/mjcf/assets/spacer__configuration_right.stl
0.0196 x 0.0047 x 0.0036

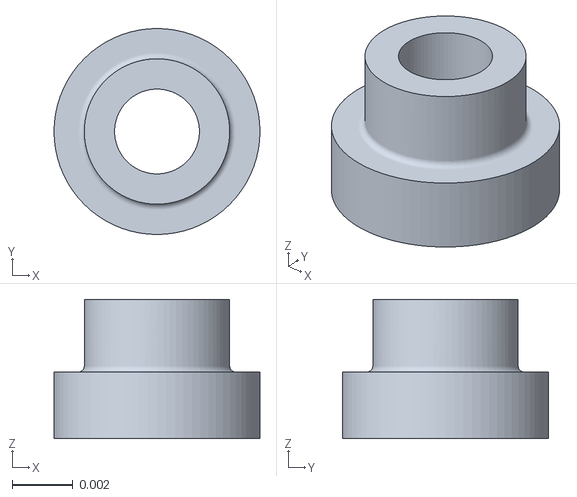
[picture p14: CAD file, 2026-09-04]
microduck/src/model/mjcf/assets/dc15_a01_idle_cap_dummy.stl
0.0068 x 0.0068 x 0.0046

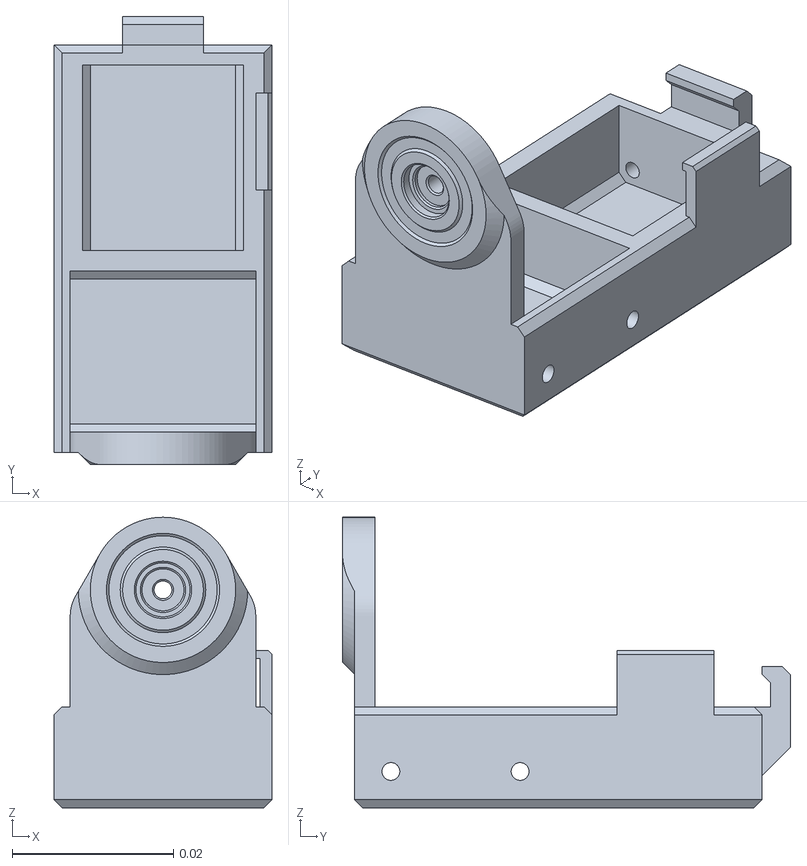
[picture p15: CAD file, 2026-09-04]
microduck/src/model/mjcf/assets/hip_dbl_block__configuration_left.stl
0.027 x 0.0555 x 0.036

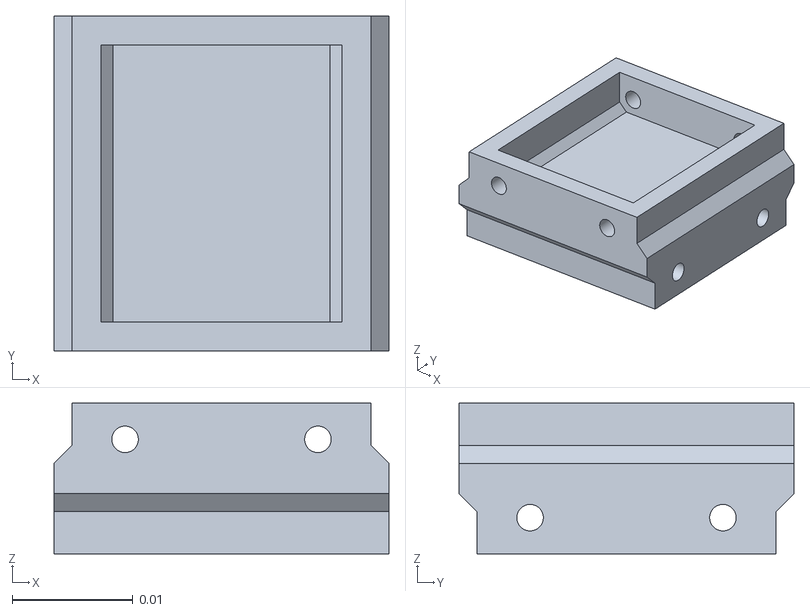
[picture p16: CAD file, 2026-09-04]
microduck/src/model/mjcf/assets/humerus.stl
0.0278 x 0.0278 x 0.0125

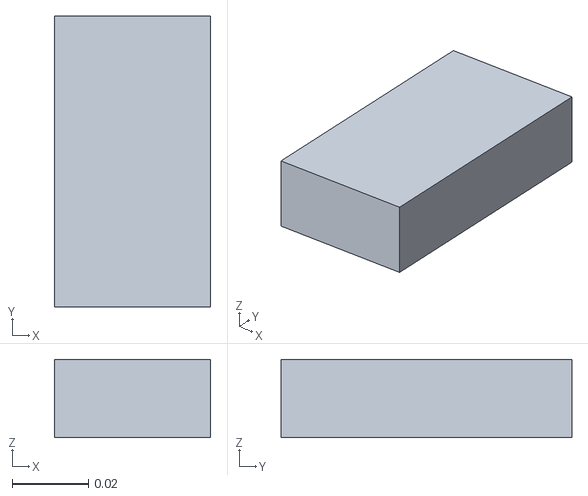
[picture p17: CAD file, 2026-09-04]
microduck/src/model/mjcf/assets/battery.stl
0.041 x 0.0763 x 0.0205

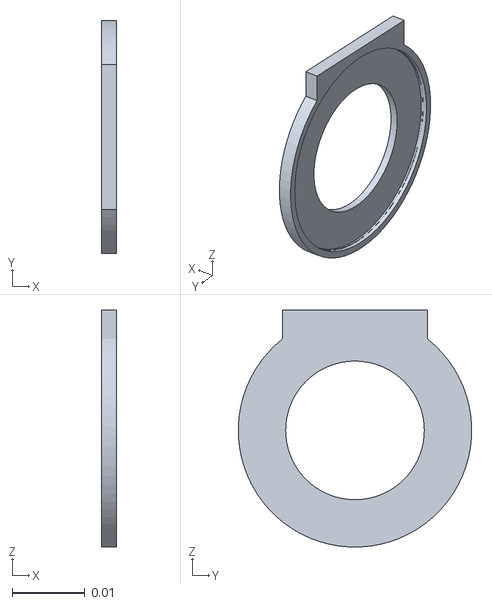
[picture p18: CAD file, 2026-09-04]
microduck/src/model/mjcf/assets/arm_bearing_support__configuration_right.stl
0.002 x 0.032 x 0.0325

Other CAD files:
microduck/src/model/mjcf/assets/tibia__configuration_right.stl
microduck/src/model/mjcf/assets/head__configuration_right.stl
microduck/src/model/mjcf/assets/xl330.stl
microduck/src/model/mjcf/assets/hip_dbl_block__configuration_right.stl
microduck/src/model/mjcf/assets/ankle_dbl_block__configuration_right.scad
microduck/src/model/mjcf/assets/femur__configuration_left.scad
microduck/src/model/mjcf/assets/femur__configuration_right.scad
microduck/src/model/mjcf/assets/foot__configuration_right.scad
microduck/src/model/mjcf/assets/ankle_dbl_block__configuration_right.stl
microduck/src/model/mjcf/assets/bts2_m2_6x8.stl
microduck/src/model/mjcf/assets/chest__configuration_right.stl
microduck/src/model/mjcf/assets/femur__configuration_left.stl
microduck/src/model/mjcf/assets/hip__configuration_right.stl
microduck/src/model/mjcf/assets/hip_dbl_block__configuration_left.scad
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

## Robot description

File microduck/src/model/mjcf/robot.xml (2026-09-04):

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
<mujoco model="microduck">
  <compiler angle="radian" meshdir="assets" autolimits="true"/>
  <default>
    <default class="microduck">
      <joint frictionloss="0.1" armature="0.005"/>
      <position kp="50" dampratio="1"/>
      <default class="visual">
        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
      </default>
      <default class="collision">
        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
      </default>
    </default>
    <default class="xl330">
      <joint damping="0.041" frictionloss="0.013" armature="0.0018"/>
      <motor gear="1"/>
    </default>
  </default>
  <sensor>
    <framequat name="orientation" objtype="site" noise="0.001" objname="imu"/>
    <gyro name="angular-velocity" site="imu" noise="0.005"/>
    <gyro name="imu_ang_vel" site="imu"/>
    <velocimeter name="imu_lin_vel" site="imu"/>
    <accelerometer name="imu_accel" site="imu"/>
    <subtreeangmom name="root_angmom" body="trunk"/>
  </sensor>
  <worldbody>
    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
    <body name="trunk" pos="0 0 0" quat="1 0 0 0" childclass="microduck">
      <freejoint name="trunk_freejoint"/>
      <inertial pos="-0.00454781 -0.000104579 0.053896" mass="0.347283" fullinertia="0.000608722 0.000477224 0.000357224 -5.1387e-07 -1.16287e-05 1.9299e-06"/>
      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
      <body name="head" pos="-0.00204165 -0 0.126" quat="0.707107 0 0 0.707107">
        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
        <joint axis="0 0 1" name="head" type="hinge" range="-1.5707963267949783 1.5707963267948148" class="xl330"/>
        <inertial pos="5.1303e-08 -0.0074561 0.0161837" mass="0.0166215" fullinertia="2.92963e-06 3.58354e-06 4.24694e-06 -1.6e-11 4e-12 2.61187e-07"/>
        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
      </body>
      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
      <body name="shoulder" pos="0 -0.0505 0.081" quat="0.707107 -0.707107 -0 0">
        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
        <joint axis="0 0 1" name="right_shoulder_pitch" type="hinge" range="-3.141592653589793 3.141592653589793" class="xl330"/>
        <inertial pos="4.19e-10 2.814e-09 -0.00850029" mass="0.00898451" fullinertia="1.06003e-06 1.78233e-06 1.86739e-06 0 0 -0"/>
        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
        <body name="humerus__configuration_right" pos="0.0145 0 -0.0195" quat="0 0.707107 0 0.707107">
          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
          <joint axis="0 0 1" name="right_shoulder_roll" type="hinge" range="-3.1415926535897922 8.881784197001252e-16" class="xl330"/>
          <inertial pos="-0.000309872 -0.0252784 -0.0143918" mass="0.0416867" fullinertia="1.76899e-05 3.95132e-06 1.75854e-05 -3.03216e-07 -2.278e-09 -7.8184e-08"/>
          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
          <body name="radius" pos="-0.0145 -0.0515 -0.0145" quat="0.707107 0 0.707107 -0">
            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
            <joint axis="0 0 1" name="right_elbow" type="hinge" range="-2.181661564992912 2.181661564992912" class="xl330"/>
            <inertial pos="-4.0628e-08 -0.0310611 0.0130165" mass="0.0115415" fullinertia="5.26775e-06 1.21602e-06 4.45903e-06 -4e-12 -1.2e-11 1.7157e-07"/>
            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
          </body>
        </body>
      </body>
      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
      <body name="hip" pos="0 -0.036 0" quat="1 -0 -0 0">
        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
        <joint axis="0 0 1" name="right_hip_yaw" type="hinge" range="-4.188790204786353 1.047197551196635" class="xl330"/>
        <inertial pos="0.00421822 1.46909e-07 -0.00948697" mass="0.00884451" fullinertia="9.36719e-07 4.32505e-06 4.03697e-06 -3.3e-11 1.95496e-07 0"/>
        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
        <body name="hip_block__configuration_right" pos="-0.02 0 -0.0214" quat="0.5 -0.5 0.5 -0.5">
          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
          <joint axis="0 0 1" name="right_hip_roll" type="hinge" range="-0.610865238197994 0.6108652381980366" class="xl330"/>
          <inertial pos="-5.75932e-05 0.00982795 0.0271518" mass="0.04763" fullinertia="1.64064e-05 1.33088e-05 7.85889e-06 -9.153e-09 7.8745e-08 6.63067e-07"/>
          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
          <body name="femur__configuration_right" pos="-0.0145 -0 0.0385" quat="0 0.707107 0 -0.707107">
            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
            <joint axis="0 0 1" name="right_hip_pitch" type="hinge" range="-1.5707963267948974 1.5707963267948957" class="xl330"/>
            <inertial pos="-0.0109472 -0.0366847 -0.0147025" mass="0.014726" fullinertia="1.12665e-05 4.38335e-06 8.95932e-06 -1.12592e-06 1.333e-09 -4.521e-09"/>
            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
            <body name="tibia__configuration_right" pos="-0.005 -0.062 -0" quat="1 -0 0 -0">
              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
              <joint axis="0 0 1" name="right_knee" type="hinge" range="-0.7853981633977201 2.356194490192073" class="xl330"/>
              <inertial pos="0.00276278 -0.0196679 -0.0144621" mass="0.0300463" fullinertia="1.53882e-05 5.3311e-06 1.38581e-05 2.25674e-06 7.6682e-08 -1.37001e-07"/>
              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
              <body name="ankle_block__configuration_left" pos="0.008 -0.0612131 -0" quat="0 -0 -0 1">
                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
                <joint axis="0 0 1" name="right_ankle_pitch" type="hinge" range="-1.5707963267948077 0.6108652381981041" class="xl330"/>
                <inertial pos="-0.0110676 -0.00979852 -0.0144015" mass="0.04722" fullinertia="7.83993e-06 1.29837e-05 1.60971e-05 -6.00742e-07 -4.9782e-08 -6.127e-09"/>
                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
                <body name="foot" pos="-0.0385 0 -0.0145" quat="0 -0.707107 0 -0.707107">
                  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
                  <joint axis="0 0 1" name="right_ankle_roll" type="hinge" range="-0.610865238197748 0.6108652381982826" class="xl330"/>
                  <inertial pos="-0 -0.0168869 0.0347422" mass="0.016823" fullinertia="1.15605e-05 1.2167e-05 2.53496e-06 0 -0 5.67932e-07"/>
                  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
                </body>
              </body>
            </body>
          </body>
        </body>
      </body>
      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
      <body name="shoulder_2" pos="-0 0.0505 0.081" quat="0 0 -0.707107 -0.707107">
        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
        <joint axis="0 0 1" name="left_shoulder_pitch" type="hinge" range="-3.141592653589793 3.141592653589793" class="xl330"/>
        <inertial pos="-4.19e-10 2.814e-09 0.00850029" mass="0.00898451" fullinertia="1.06003e-06 1.78233e-06 1.86739e-06 -0 0 0"/>
        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
        <body name="humerus__configuration_left" pos="-0.0145 0 0.0195" quat="0 -0.707107 -0 0.707107">
          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
          <joint axis="0 0 1" name="left_shoulder_roll" type="hinge" range="0.0 3.141592653589793" class="xl330"/>
          <inertial pos="-0.000313281 0.0252784 -0.0143884" mass="0.0416867" fullinertia="1.76899e-05 3.9512e-06 1.75853e-05 3.01684e-07 -5.77e-10 7.6531e-08"/>
          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
          <body name="radius_2" pos="-0.0145 0.0515 -0.0145" quat="0.707107 0 -0.707107 0">
            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
            <joint axis="0 0 1" name="left_elbow" type="hinge" range="-2.1816615649929156 2.1816615649929085" class="xl330"/>
            <inertial pos="-4.0628e-08 0.0310611 -0.0130165" mass="0.0115415" fullinertia="5.26775e-06 1.21602e-06 4.45903e-06 4e-12 1.2e-11 1.7157e-07"/>
            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
          </body>
        </body>
      </body>
      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
      <body name="hip_2" pos="-0 0.036 0" quat="0 -0 0 -1">
        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
        <joint axis="0 0 1" name="left_hip_yaw" type="hinge" range="-1.0471975511965976 4.1887902047863905" class="xl330"/>
        <inertial pos="-0.00421822 -1.46909e-07 -0.00948697" mass="0.00884451" fullinertia="9.36719e-07 4.32505e-06 4.03697e-06 -3.3e-11 -1.95496e-07 -0"/>
        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
        <body name="hip_block__configuration_left" pos="0.02 0 -0.0214" quat="0.5 -0.5 -0.5 0.5">
          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
          <joint axis="0 0 1" name="left_hip_roll" type="hinge" range="-0.6108652381980162 0.6108652381980144" class="xl330"/>
          <inertial pos="6.0554e-05 0.00982795 0.0271548" mass="0.04763" fullinertia="1.64096e-05 1.3312e-05 7.85888e-06 8.495e-09 -7.6959e-08 6.62404e-07"/>
          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
          <body name="femur__configuration_left" pos="-0.0145 -0 0.0385" quat="0.707107 -0 -0.707107 0">
            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
            <joint axis="0 0 1" name="left_hip_pitch" type="hinge" range="-1.5707963267948974 1.5707963267948957" class="xl330"/>
            <inertial pos="0.0109472 0.0366847 -0.0142975" mass="0.014726" fullinertia="1.12665e-05 4.38335e-06 8.95932e-06 -1.12592e-06 1.333e-09 -4.521e-09"/>
            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
            <body name="tibia__configuration_left" pos="0.005 0.062 0" quat="1 -0 -0 -0">
              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

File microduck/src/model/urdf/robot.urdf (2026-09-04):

<?xml version="1.0" ?>
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
<robot name="urdf">
  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
  <link name="trunk">
    <inertial>
      <origin xyz="-0.00454781 -0.000104579 0.053896" rpy="0 0 0"/>
      <mass value="0.347283"/>
      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
    </inertial>
    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
  </link>
  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
  <link name="body">
    <origin xyz="0 0 0" rpy="0 -0 0"/>
    <inertial>
      <origin xyz="0 0 0" rpy="0 0 0"/>
      <mass value="1e-9"/>
      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
    </inertial>
  </link>
  <joint name="body_frame" type="fixed">
    <origin xyz="0 0 0" rpy="0 0 0"/>
    <parent link="trunk"/>
    <child link="body"/>
    <axis xyz="0 0 0"/>
  </joint>
  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
  <link name="imu">
    <origin xyz="0 0 0" rpy="0 -0 0"/>
    <inertial>
      <origin xyz="0 0 0" rpy="0 0 0"/>
      <mass value="1e-9"/>
      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
    </inertial>
  </link>
  <joint name="imu_frame" type="fixed">
    <origin xyz="0.01483 -0.002 0.0675" rpy="1.5708 -0 -1.5708"/>
    <parent link="trunk"/>
    <child link="imu"/>
    <axis xyz="0 0 0"/>
  </joint>
  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
  <link name="head">
    <inertial>
      <origin xyz="5.1303e-08 -0.0074561 0.0161837" rpy="0 0 0"/>
      <mass value="0.0166215"/>
      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
    </inertial>
    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
  </link>
  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
  <joint name="head" type="revolute">
    <origin xyz="-0.00204165 -0 0.126" rpy="0 0 1.5708"/>
    <parent link="trunk"/>
    <child link="head"/>
    <axis xyz="0 0 1"/>
    <limit effort="10" velocity="10" lower="-1.5708" upper="1.5708"/>
  </joint>
  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
  <link name="shoulder">
    <inertial>
      <origin xyz="4.19e-10 2.814e-09 -0.00850029" rpy="0 0 0"/>
      <mass value="0.00898451"/>
      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
    </inertial>
    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
  </link>
  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
  <link name="humerus__configuration_right">
    <inertial>
      <origin xyz="-0.000309872 -0.0252784 -0.0143918" rpy="0 0 0"/>
      <mass value="0.0416867"/>
      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
    </inertial>
    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
  </link>
  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
  <link name="radius">
    <inertial>
      <origin xyz="-4.0628e-08 -0.0310611 0.0130165" rpy="0 0 0"/>
      <mass value="0.0115415"/>
      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
    </inertial>
    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
  </link>
  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
  <joint name="right_elbow" type="revolute">
    <origin xyz="-0.0145 -0.0515 -0.0145" rpy="-0 1.5708 0"/>
    <parent link="humerus__configuration_right"/>
    <child link="radius"/>
    <axis xyz="0 0 1"/>
    <limit effort="10" velocity="10" lower="-2.18166" upper="2.18166"/>
  </joint>
  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
  <joint name="right_shoulder_roll" type="revolute">
    <origin xyz="0.0145 0 -0.0195" rpy="-3.14159 -1.5708 0"/>
    <parent link="shoulder"/>
    <child link="humerus__configuration_right"/>
    <axis xyz="0 0 1"/>
    <limit effort="10" velocity="10" lower="-3.14159" upper="0"/>
  </joint>
  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
  <joint name="right_shoulder_pitch" type="revolute">
    <origin xyz="0 -0.0505 0.081" rpy="-1.5708 0 0"/>
    <parent link="trunk"/>
    <child link="shoulder"/>
    <axis xyz="0 0 1"/>
    <limit effort="10" velocity="10" lower="-3.14159" upper="3.14159"/>
  </joint>
  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
  <link name="hip">
    <inertial>
      <origin xyz="0.00421822 1.46909e-07 -0.00948697" rpy="0 0 0"/>
      <mass value="0.00884451"/>
      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
    </inertial>
    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
  </link>
  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
  <link name="hip_block__configuration_right">
    <inertial>
      <origin xyz="-5.75932e-05 0.00982795 0.0271518" rpy="0 0 0"/>
      <mass value="0.04763"/>
      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
    </inertial>
    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
  </link>
  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
  <link name="femur__configuration_right">
    <inertial>
      <origin xyz="-0.0109472 -0.0366847 -0.0147025" rpy="0 0 0"/>
      <mass value="0.014726"/>
      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
    </inertial>
    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
  </link>
  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
  <link name="tibia__configuration_right">
    <inertial>
      <origin xyz="0.00276278 -0.0196679 -0.0144621" rpy="0 0 0"/>
      <mass value="0.0300463"/>
      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
    </inertial>
    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
  </link>
  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
  <link name="ankle_block__configuration_left">
    <inertial>
      <origin xyz="-0.0110676 -0.00979852 -0.0144015" rpy="0 0 0"/>
      <mass value="0.04722"/>
      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
    </inertial>
    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
  </link>
  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
  <link name="foot">
    <inertial>
      <origin xyz="-0 -0.0168869 0.0347422" rpy="0 0 0"/>
      <mass value="0.016823"/>
      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
    </inertial>
    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
  </link>
  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
  <link name="right_foot">
    <origin xyz="0 0 0" rpy="0 -0 0"/>
    <inertial>
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

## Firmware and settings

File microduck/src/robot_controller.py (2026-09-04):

# SPDX-License-Identifier: GPL-3.0-or-later
# Copyright 2026 Marc Duclusaud

from rustypot import Xl330PyController
import glob
import os
import numpy as np

from constants import MOTOR_TO_ID, MOTOR_OFFSET, MOTOR_SIGN, IMU_I2C_BUS, PRESENT_CURRENT_UNIT_A
from imu_reader import ThreadedIMUReader


def resolve_serial_port(serial_port: str) -> str:
    if serial_port != "auto":
        return serial_port
    candidates = (
        sorted(glob.glob("/dev/serial/by-id/usb-ROBOTIS_OpenRB-150_*"))
        + ["/dev/ttyACM0", "/dev/serial0", "/dev/ttyAMA0", "/dev/ttyS0"]
    )
    for path in candidates:
        if os.path.exists(path):
            return path
    return "/dev/ttyAMA0"


class RobotController:
    """Wraps Xl330PyController."""

    def __init__(self, serial_port: str = "auto", baudrate: int = 1_000_000, timeout: float = 0.1) -> None:
        serial_port = resolve_serial_port(serial_port)
        print(f"Using Dynamixel serial port: {serial_port}", flush=True)
        self._controller = Xl330PyController(serial_port=serial_port, baudrate=baudrate, timeout=timeout)
        self._id_to_sign: dict[int, float] = {MOTOR_TO_ID[name]: MOTOR_SIGN[name] for name in MOTOR_TO_ID}
        self._id_to_offset: dict[int, float] = {MOTOR_TO_ID[name]: MOTOR_OFFSET[name] for name in MOTOR_TO_ID}
        self._imu_reader = ThreadedIMUReader(i2c_bus=IMU_I2C_BUS, frequency_hz=50.0)
        self._imu_reader.start()

    def sync_write_torque_enable(self, ids: list[int], values: list[bool]) -> None:
        self._controller.sync_write_torque_enable(ids, values)

    def sync_write_status_return_level(self, ids: list[int], levels: list[int]) -> None:
        self._controller.sync_write_status_return_level(ids, levels)

    def sync_write_goal_position(self, ids: list[int], positions: list[float]) -> None:
        hw_positions = [
            pos * self._id_to_sign[motor_id] + self._id_to_offset[motor_id]
            for motor_id, pos in zip(ids, positions)
        ]
        self._controller.sync_write_goal_position(ids, hw_positions)

    def sync_read_present_position(self, ids: list[int]) -> list[float]:
        raw = self._controller.sync_read_present_position(ids)
        return [
            (r - self._id_to_offset[motor_id]) * self._id_to_sign[motor_id]
            for motor_id, r in zip(ids, raw)
        ]

    def read_present_position(self, motor_id: int) -> float:
        raw = self._controller.read_present_position(motor_id)
        raw_value = raw[0] if isinstance(raw, (list, tuple)) else float(raw)
        return (raw_value - self._id_to_offset[motor_id]) * self._id_to_sign[motor_id]

    def sync_read_present_velocity(self, ids: list[int]) -> list[float]:
        raw = np.array(self._controller.sync_read_present_velocity(ids)) * 0.229 * np.pi / 30
        return [r * self._id_to_sign[motor_id] for motor_id, r in zip(ids, raw)]
    
    def read_present_velocity(self, motor_id: int) -> float:
        raw = self._controller.read_present_velocity(motor_id) * 0.229 * np.pi / 30
        return raw * self._id_to_sign[motor_id]

    def sync_read_present_current(self, ids: list[int]) -> list[float]:
        """Present current per motor, in Amps (signed). Magnitude is what matters for the BMS budget."""
        raw = self._controller.sync_read_present_current(ids)
        return [
            (r[0] if isinstance(r, (list, tuple)) else float(r)) * PRESENT_CURRENT_UNIT_A
            for r in raw
        ]

    def sync_read_present_input_voltage(self, ids: list[int]) -> list[float]:
        raw = self._controller.sync_read_present_input_voltage(ids)
        return [r[0] if isinstance(r, (list, tuple)) else float(r) for r in raw]

    def read_present_input_voltage(self, motor_id: int) -> float:
        raw = self._controller.read_present_input_voltage(motor_id)
        return raw[0] if isinstance(raw, (list, tuple)) else float(raw)

    def sync_read_kp(self, ids: list[int]) -> list[int]:
        return [int(v) for v in self._controller.sync_read_position_p_gain(ids)]

    def sync_write_kp(self, ids: list[int], gains: list[int]) -> None:
        self._controller.sync_write_position_p_gain(ids, gains)

    def read_acc(self) -> tuple[float, float, float]:
        """Return raw accelerometer (ax, ay, az) in g."""
        return self._imu_reader.get_latest().acc

    def read_gyro(self) -> tuple[float, float, float]:
        """Return (gx, gy, gz) in rad/s."""
        return self._imu_reader.get_latest().gyro

    def read_quat(self, dt: float) -> tuple[float, float, float, float]:
        """Return orientation quaternion (w, x, y, z)."""
        _ = dt
        return self._imu_reader.get_latest().quat

    def get_imu_status(self) -> dict[str, float | int | bool]:
        return self._imu_reader.get_status()

    def shutdown(self) -> None:
        self._imu_reader.stop()

    def close(self) -> None:
        self.shutdown()

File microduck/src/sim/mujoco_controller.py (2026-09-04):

# SPDX-License-Identifier: GPL-3.0-or-later
# Copyright 2026 Marc Duclusaud

import time
from collections import deque
from collections.abc import Callable
from pathlib import Path
from typing import TYPE_CHECKING

import mujoco
import mujoco.viewer

if TYPE_CHECKING:
    from sim.mujoco_input import MuJoCoInputSource

from bam.model import load_model as bam_load_model
from bam.mujoco import MujocoController as BamController

from constants import MOTOR_TO_ID, ID_TO_MOTOR, NEUTRAL_POSE, KP_DEFAULT, BAM_VIN, BAM_VOLTAGE_DROP_GAIN, BAM_VIN_MIN, BAM_MAX_CURRENT


class _DelayBuffer:
    """Returns values delayed by n_steps ticks (0 = no delay)."""

    def __init__(self, initial, n_steps: int) -> None:
        size = max(1, n_steps + 1)
        self._buf: deque = deque([initial] * size, maxlen=size)

    def push_and_read(self, value):
        self._buf.appendleft(value)
        return self._buf[-1]

    def fill(self, value) -> None:
        for i in range(len(self._buf)):
            self._buf[i] = value


class MuJoCoController:
    """MuJoCo-backed controller."""

    def __init__(
        self,
        mjcf_path: str,
        key_callback: Callable[[int, int, int, int], None] | None = None,
        stop_flag_path: str = "/tmp/microduck_scheduler.stop",
        reset_source: "MuJoCoInputSource | None" = None,
        # Actuation delay (command → motor), in simulator steps (default timestep: 0.005 s)
        delay_act_steps: int = 0,
        # Sensor delays (motor/IMU → observation), in scheduler ticks (default: 0.02 s)
        delay_pos_ticks: int = 0,
        delay_vel_ticks: int = 0,
        delay_gyro_ticks: int = 0,
        delay_quat_ticks: int = 0,
        trunk_com_offset: tuple[float, float, float] = (0.0, 0.0, 0.0),
    ) -> None:
        self._stop_flag_path = Path(stop_flag_path)
        self._reset_source = reset_source
        self._model = mujoco.MjModel.from_xml_path(mjcf_path)
        self._data = mujoco.MjData(self._model)

        self._name_to_actuator_idx: dict[str, int] = {}
        self._name_to_qpos_idx: dict[str, int] = {}
        self._name_to_qvel_idx: dict[str, int] = {}
        for name in MOTOR_TO_ID:
            actuator_id = mujoco.mj_name2id(self._model, mujoco.mjtObj.mjOBJ_ACTUATOR, name)
            joint_id = mujoco.mj_name2id(self._model, mujoco.mjtObj.mjOBJ_JOINT, name)
            if actuator_id < 0:
                raise ValueError(f"Actuator '{name}' not found in MJCF model {mjcf_path!r}")
            if joint_id < 0:
                raise ValueError(f"Joint '{name}' not found in MJCF model {mjcf_path!r}")
            self._name_to_actuator_idx[name] = actuator_id
            self._name_to_qpos_idx[name] = self._model.jnt_qposadr[joint_id]
            self._name_to_qvel_idx[name] = self._model.jnt_dofadr[joint_id]
        # Number of physics sub-steps per scheduler tick (scheduler runs at 50 Hz)
        self._steps_per_tick = max(1, round(0.02 / self._model.opt.timestep))
        self._torque_interval = 0.1
        self._last_torque_print = 0.0

        # Apply CoM offset on trunk body (simulates inertial model error)
        if any(v != 0.0 for v in trunk_com_offset):
            trunk_id = mujoco.mj_name2id(self._model, mujoco.mjtObj.mjOBJ_BODY, "trunk")
            self._model.body_ipos[trunk_id, 0] += trunk_com_offset[0]
            self._model.body_ipos[trunk_id, 1] += trunk_com_offset[1]
            self._model.body_ipos[trunk_id, 2] += trunk_com_offset[2]

        # Set initial pose to neutral so the robot starts upright
        self._data.qpos[2] = 0.165
        for name, angle in NEUTRAL_POSE.items():
            if name in self._name_to_qpos_idx:
                self._data.qpos[self._name_to_qpos_idx[name]] = angle
        mujoco.mj_forward(self._model, self._data)

        # Delay buffers — simulate sensor/communication latency
        self._delay_pos = {
            mid: _DelayBuffer(
                self._data.qpos[self._name_to_qpos_idx[ID_TO_MOTOR[mid]]],
                delay_pos_ticks,
            )
            for mid in MOTOR_TO_ID.values()
        }
        self._delay_vel = {
            mid: _DelayBuffer(0.0, delay_vel_ticks)
            for mid in MOTOR_TO_ID.values()
        }
        self._delay_gyro = _DelayBuffer((0.0, 0.0, 0.0), delay_gyro_ticks)
        self._delay_quat = _DelayBuffer((1.0, 0.0, 0.0, 0.0), delay_quat_ticks)
        self._delay_act = {
            mid: _DelayBuffer(
                self._data.qpos[self._name_to_qpos_idx[ID_TO_MOTOR[mid]]],
                delay_act_steps,
            )
            for mid in MOTOR_TO_ID.values()
        }

        # BAM motor model — XL330 m6 (DC motor + Stribeck + load-dependent friction)
        bam_model = bam_load_model(motor_name="xl330", model="m6")
        bam_model.actuator.kp = KP_DEFAULT
        bam_model.actuator.vin = BAM_VIN
        self._bam = BamController(
            bam_model,
            list(MOTOR_TO_ID.keys()),
            self._model,
            self._data,
            vin_drop_gain=BAM_VOLTAGE_DROP_GAIN,
            vin_min=BAM_VIN_MIN,
            max_current=BAM_MAX_CURRENT,
        )
        self._bam.reset(self._data.qpos)

        self._viewer = mujoco.viewer.launch_passive(
            self._model, self._data, key_callback=key_callback
        )

        # Sensor indices for IMU readout
        self._sensor_orientation = mujoco.mj_name2id(self._model, mujoco.mjtObj.mjOBJ_SENSOR, "orientation")
        self._sensor_gyro = mujoco.mj_name2id(self._model, mujoco.mjtObj.mjOBJ_SENSOR, "angular-velocity")

    @property
    def viewer_opt(self) -> mujoco.MjvOption:
        return self._viewer.opt

    def set_kp(self, kp: float) -> None:
        self._bam.model.actuator.kp = kp

    def sync_read_kp(self, ids: list[int]) -> list[int]:
        kp = int(self._bam.model.actuator.kp)
        return [kp] * len(ids)

    def sync_write_kp(self, ids: list[int], gains: list[int]) -> None:
        self._bam.model.actuator.kp = gains[0]

    def sync_write_torque_enable(self, ids: list[int], values: list[bool]) -> None:
        pass

    def sync_write_status_return_level(self, ids: list[int], levels: list[int]) -> None:
        pass

    def sync_write_goal_position(self, ids: list[int], positions: list[float]) -> None:
        if not self._viewer.is_running():
            self._stop_flag_path.write_text("stop\n", encoding="ascii")
            return

        cmd = dict(zip(ids, positions))

        for _ in range(self._steps_per_tick):
            for motor_id, pos in cmd.items():
                delayed_pos = self._delay_act[motor_id].push_and_read(pos)
                self._bam.set_q_target(ID_TO_MOTOR[motor_id], delayed_pos)
            self._bam.update()
            mujoco.mj_step(self._model, self._data)

        if self._reset_source is not None and self._reset_source.consume_reset():
            self.reset()
            return
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

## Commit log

2026-09-04 Add Microduck build tutorial
    [ankle_dbl_block.step, ankle_dbl_block.stl, ankle_dbl_block__configuration_right.scad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]
2026-09-05 Add README demo GIFs at the top.
    Show exploded CAD, human-robot interaction, and real walking first so the project is visible immediately.
2026-09-07 3D打印文件
    [microduck3D打印.3mf]

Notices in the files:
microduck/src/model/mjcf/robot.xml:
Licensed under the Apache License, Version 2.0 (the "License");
